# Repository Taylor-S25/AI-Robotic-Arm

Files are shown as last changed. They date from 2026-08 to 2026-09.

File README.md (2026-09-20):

# Robotic-Arm/Gripper

Design and development of an Arduino controlled robotic arm/gripper

### Introduction & Goals

Inspired by Iron Man, this project explores the design of a robotic arm and how it can act as an extra pair of hands for simple tasks. The project combines mechanical design, CAD, prototyping and electronic control, with the long-term goal of exploring AI-assisted control.

The Problem this project it trying to address is fatigue. This robotic arm is to provide assistance to the user hence they can receive an extra pair of hands when needed. 

This project is currently in the last stage of its development as the assembly just needs to be upgraded with servo control as I am currently waiting for ordered parts. 

Tools, components and manufacturing methods:
- PTC Creo for CAD development
- 3D printing for manufacture
- Velxio for simulation control
- Arduino, servomotors and potentiometers for motion control
- GitHub for Project documentation 

Final outcome: A working robotic gripper assembly with servo motor control. Designed in Creo, tolerance tested through 3D printing iterations, and documented on GitHub

Goal 1: Robotic Arm must achieve mechanical motion 
 Result: The servomotors rotated the elbow joints by at least 60 degrees

Goal 2: Fabricte a physical prototype 
  Result: CAD components were 3D printed 

Goal 3: Implement basic control circuitry  
  Result: wired a potentiometer to a servomotor and controlled it with an Arduino  

## Initial Architecture design and features
<p align="center">
  
  
</p>
Early concept sketch showing arm structure joint movement and gripper mechanism.

# Contents

- [Project Overview & Requirements](#Project-Overview--Requirements)
- [Constraints](#Constraints)
- [Used Tools & Components](#Used-Tools--Components)
  - [CAD & Mechanical Design](#CAD--Mechanical-Design)
  - [Actuation, Electronics & Control](#Actuation-Electronics--Control)
  - [Manufacturing & Prototyping](#Manufacturing--Prototyping)
  - [Version Control & Documentation](#Version-Control--Documentation)
      - [Repository Structure](#Repository-Structure)
- [Design Development & Iteration](#Design-Development--Iteration)
  - [Tolerances, Fits & Interfaces](#tolerances-fits--interfaces)
- [Testing & Validation](#Testing--Validation)
- [Demo](#Demo)
- [What Breaks / Current Limitations](#What-Breaks--Current-Limitations)
- [Future Development](#Future-Development)
- [Conclusion](#Conclusion)

## Project Overview & Requirements

The Robotic arm/gripper is intended to be able to pick up and move small lightweight objects using servocontrolled motion. The project has been designed to have 4 joint and 5 degrees of freedom. The current version is only has 4 degrees of freedom and 3 joints with the ability to move with servomotor control. The project current stage is fully developed. The Robotic arms requirements are:

- to move at least 60 degrees of motion at each joint
- to be a physical model
- to cost no more than £50
- to use circuitry
- to be able to pick up and grip objects
- to have at least 2 degrees of freedom
- to have appropriate measurements
- to have appropriate coding

I have met the first requirement due to my [final demo](#Demo) which demonstrates that the robotic arm prototype can move 64 degrees. I have also met the second, third and forth requirements as I have 3D printed my robotic arm and have used circuitry such as microcontrollers, servomotors and potentiometers to bring my design to life, whilst keeping under my budget. Requirements 6 and 7 have also been met as the final products shows at least 2 degrees of freedom and appropriate measurements due a clearance of ±0.4mm being used.

Requirements I haven't met are 5 and 8 as I didn't have the money to 3D print the robotic gripper head meaning that only a simulation could be shown to display its objected lifting capabilities meaning that this requirement can't be completely validated. Therefore if I had to redo the project I would make a physical gripper head to validate this. Another requirement I didn't meet was appropriate coding as I used AI to create this C++ code, I haven't learned how to use C yet although I do know how to use Python and MATLABS. Hence, if I had to redo the project I would learn to use C++ before hand so I could validate this programming as my own.

## Constraints

Budget: £50 was the maximum amount of money I was willing to spend on this project. This stopped me from being able to 3D print the gripper head of the robotic arm, as I would have gone over budget. Hence I could only 3D print the body for the prototype. Therefore, I decided to simulate how the gripper works as a substitute. 

Time: The projects deadline was mid September 2026 with a project window frame of about 6 weeks

Hardware: For this project, I worked primarily with a standard Laptop and iPad. This limited me in simulating how my Robotic arm would react to stress and thermal analysis as simulation required an NVIDIA GPU. furthermore, this project caused me to borrow Arduino, servomotors, potentiometers and more from my university. 

Manufacturing: Manufacturing for the robotic arm was completed at my university as I didn't own a 3D printer. Black PLA filament was used for modelling. CAD parts were turned into STL files and exported to the device using a flash drive which I had to purchase, reducing my budget.

Geometry / packaging: The robotic arm was limited due to the size of the wings on each servomotor. Hence I had to order servo linkages off Amazon to attach each members to each servomotor causing a reduction in my budget that could have been spent else where.

Safety / reliability: Safety and reliability limits involved the circuitry not being built into the robotic arms design. Hence loose wiring occurring was greater meaning that the devices function could fail. 

## Used Tools & Components

- PTC Creo was used for CAD as I already knew how to use this software. Creo covers modelling, assemblies and drawings in one place making it a good choice for the robotic arms design. An alternative I thought about using was SolidWorks as I have experience with this software but haven’t used it in 2 years hence, I chose Creo.
 
- 3D printing was used to physically manifest parts. This went hand in hand with my CAD modelling as I could copy the designs into STL files used for quick and easy printing. Making it the strongest option. An alternative I thought about was cutting foam using a hot wire cutter, but this wouldn’t have been passive work and would have taken up a lot of time meaning I could have fallen behind schedule.
  
- Arduino was used for driving the servomotors when an input was given to the potentiometers. This allowed me to control the rotation of the robotic arm’s members. Components were connected via wiring through a breadboard. An alternative I thought about using was a Raspberry Pi, but this was far too complex than what I needed.
  
- Servomotors were used for controlling the members of the robotic arm. These were connected to each member via metal rods. An alternative I thought about using was a DC motor, but its torque was too low.
  
- GitHub was used to document my project as it provided branching which allowed me to update my progress without affecting the main database until I was ready.
  
- Velxio was a simulator I used for designing my circuitry before I assembled it physically. This helped me to design it physically

[AI Arduino source code](Physical%20and%20software%20simulations/sketch.ino)  
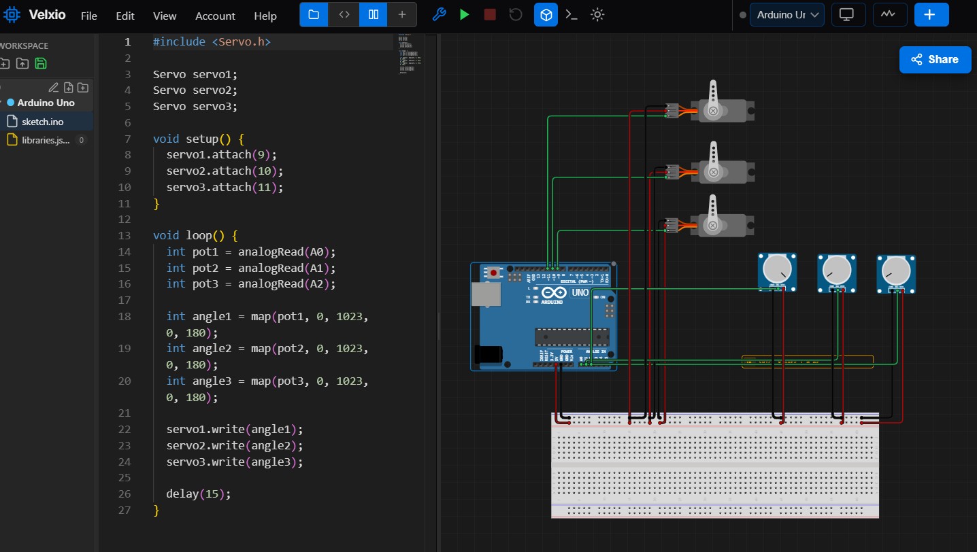
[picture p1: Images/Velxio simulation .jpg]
Velxio simulation


## CAD & Mechanical Design

CAD software used: PTC Creo, was used as it was the software I have the most expirience with. 

Overall assembly: The Over all assembly features around 20+ parts with some parts being used more than once. Two assemblies were created the gripper head and the Robotic arm. The mechanism had 5 degrees of freedom. 
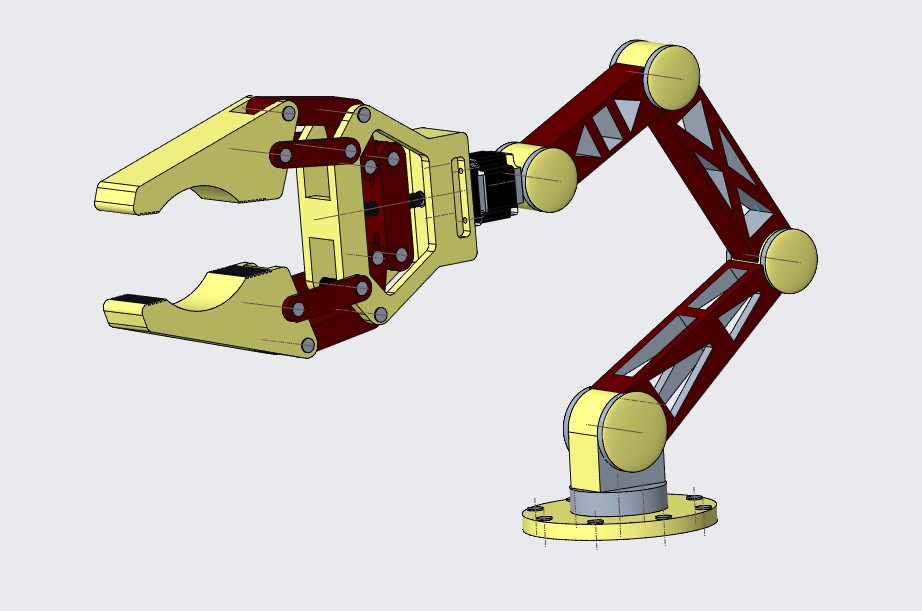
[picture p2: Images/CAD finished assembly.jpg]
CAD Assembly


Key mechanisms: Gripper assembly, small arm, medium arm, large arm, base joint, base plate

Motion / mechanism analysis: Checked rotary motion at each joint, at extreme angles there were limits but this was a desired outcome to avoid clashing.

Engineering drawings: All the [3D printing parts](3D%20printing%20parts/) needed drawing due to tolerancing required for smooth connections when 3D printing.

Design trade-offs: To ensure that the members were as light as possible, for smoother servomotor control, this involved removing as much material as possible making the parts weaker. However, this made the cost to print cheaper saving money. 

Alternative designs considered: Only using a 2 member design was something I had considered as it made the design more simplistic and cheap. However this reduced the robotic arms reach making it less practical. Therefore, I gave the design 3 members. For the gripper head I thought about using gears but this seemed too complicated for the design so I stuck with servo driven motion. 

## Actuation, Electronics & Control

Microcontroller: ELEGO UNOR3 - its role was to turn code into a set of instructions between the potentiometer and the servomotor causing motion. This was suitable as it provided enough voltage and amplitude for the job.

Actuators: Used standard hobby servomotor model S3003 for simple motion control

User input: Turning Potentiometer 

Power: The circuitry was powered via my laptop and a booster I bought to prevent the microcontroller's fuse from blowing

Wiring: Standard ELEGO male-male wiring was used to connect each component to the breadboard

Control logic: Input (potentiometer is turned), microcontroller (ELEGO processes input to produce the required output using code), Output (servomotor rotates)
### physical Arduino-servo simulation
https://github.com/user-attachments/assets/86161a06-1482-4143-b839-d0289b86b35f

safety limits: servomotors were placed inside members to prevent damage and servo-rotation was limited to prevent collisions.

## Manufacturing & Prototyping

As there were so many parts to print, this would have cost a lot of money, hence I could only print the main parts of the robotic arm. This excluded bearings and rods as well as the gripper head.  The gripper head was very intricate and would have taken a lot of time and resources to print, so I simulated it instead. Manufacturing limitations led to me altering the original parts making them easier to 3D print. As hovering displayed in the initial designs would have caused the software to produce lots of supports causing rough surfaces and greater friction reducing smooth servo control. 

Parts were assembled and disassembled due to panels pinned at each joint which ensured the members stayed connected. Each connection point had a tolerance of ± 0.4mm so everything attached smoothly. On my first print of the Robotic arm failed to integrate this, hence reprints were done. The cost for this was around about £20 worth of materials for both sets of prints. 

### Initial 3D print failure


## Version Control & Documentation

Explain how GitHub is used to organise the project. GitHub has been the central place for where I have organised all my work. I have structured files for CAD, 3D printing, Images, modifications and simulations. I have used the README to explain, what I did in the project as well as how and why for a plethora of decisions.

### Repository Structure
- STL files modified for 3D printing can be found [here](3D%20printing%20parts/)
- CAD parts and assemblies can be found in the working directory [here](Creo%20project/)
- Images documenting the project can be found [here](Images/)
- Modified Parts for clearance, cost and weigh can be found [here](Modified%20parts%20for%20tolerances/)
- Simulations for CAD, Arduino and the final product can be found [here](Physical%20and%20software%20simulations/)
- README for the project story: goals, decisions, evidence, results, limitations and next steps can be found [here](README.md)

By using branches I updated a copy of the main repository. This allowed me to edit my README and filing by adding or deleting things. If I liked the work I completed with this branch, I could then merge it with the original to make it the main branch. If I didn't I could then discard the branch whilst keeping the initial main the same.

Each edit caused by pushing new material to the origin was apart of my iterative design and if you go to my profile you can see all of the tweaks I made to this project throughout its life.

## Tolerances, Fits & Interfaces

Initially all the connected parts for the Robotic arm had no clearance. Using a clearance was something I probably should have thought about in the initial 3D print. This meant that the first print was too tight causing a lot of friction stopping smooth servomotor control. This led to me to modify CAD parts for manufacturing purposes. This involved removing material for light weight and cost and using a clearance of ±0.4mm. This made it easier for the servomotors to move and lift the adjacent material. This helped me to learn that every time you design something, a tolerance should always be used in manufacture, otherwise components may not fit together as designed.

## Testing & Validation

Testing was completed non-destructively. Non-destructively the objective was to see if the project could rotate at least 60 degrees, this was mentioned at the start in my goals. To measure this I used a protractor the arm manage to move around 64 degrees and couldn't move any further. A limitation was the servomotors as they could only rotate 180 degrees. If I had to do the test again i would have used a different type of servomotor that could move 360 degrees. Hence each member would have been able to rotate further.

Furthermore, I used non-destructive testing to assess the gripper head this was using CAD software as I couldn't 3D print the gripper. The objective was to use a servomotor to get the jaws of the gripper head to open and close. 

https://github.com/user-attachments/assets/3b3507d3-5217-4580-a304-04e4b8625a54

The result was that the gripper could open and close prefectly. A limitation of this is that I couldn't produce it physically hence I don't know truly if it would work. Therefore, if I had to do redo the project I would get more funding to print out the gripper. 

## Demo

This is a demo of the final product it shows me moving two of the robotic arms members using potentiometers and servomotors connected via a breadboard and microcontroller. This was were my robotic arm cam to life!

### Robotic Arm Project Final Demonstration
https://github.com/user-attachments/assets/79b7d7dd-8787-4b34-adfd-126fe1583319

## What Breaks / Current Limitations

-	One limit I reached was using more than 2 servomotors for the main prototype I would have liked to use 4. However, this would have involved massive changes CAD design and manufacture to allow for the servomotors to be integrated into the base plate and base joints. Hence if I had to produce a 3rd model, I would do that.
  
-	Another limit was the gripper head being printed. This would have taken a lot of time and money to produce due to there being so many parts. Hence if I had to produce another prototype, I would have increase my budget and extended my deadlines, to account for a clearance alteration, the time taken and cost to print.
  
- Currently nothing destructively breaks but servo motion is limited as there on no slots for the servos to work smoothly with. Theis is due to metal rods connecting the servos to each member become tight. This puts pressure on the servomotors causing them to move themselves as they aren’t fixed. Hence, for my next version I will fix the servos and add a slot in each member for the rods to move in.

## Future Development

Mechanical improvement: To 3D print the gripper head and attach it to the gripper arm so it looks more like the CAD model

Electronics improvement: To add additional servomotors and using slotting for better servo motion 

Additional testing: To simulate the gripper head physically and not just on CAD.

Long-term development: To use AI-assisted control - use and AI to decide whether the robotic arm should pick something up or not.

## Conclusion

Overall, this project has provided an opportunity to apply the engineering design process from an initial design to a functional prototype. Looking back at my 3 goals I managed to achieve all of them as I created a robotic gripper which could rotate at least 60 degrees, fabricated a physical prototype and used basic circuitry in the final design.

Major engineering decisions that made the biggest difference was using a clearance and removing material for a lighter and cheaper product. This iteration allowed me to save money and produce smooth servomotor control and taught me to apply these things straight away for future projects.

Something that the Prototyping taught me that CAD alone did not was that using a clearance in a physical prototype is imperative whereas in a CAD assembly it is not. Hence, always account for real world problems as a stimulatory drawing cannot account for every issue.

The biggest challenge I faced was using circuitry as I have never been taught mechatronics. Therefore, this was a challenge that taught me a lot about microcontrollers and circuits. Hence, I now feel more confident in using them now and in the future. 

If I had to start the project again and change something I would give myself a larger time frame and a bigger budget to complete the robotic arm/gripper. As then I might have been able to make the gripper giving the project greater validation.

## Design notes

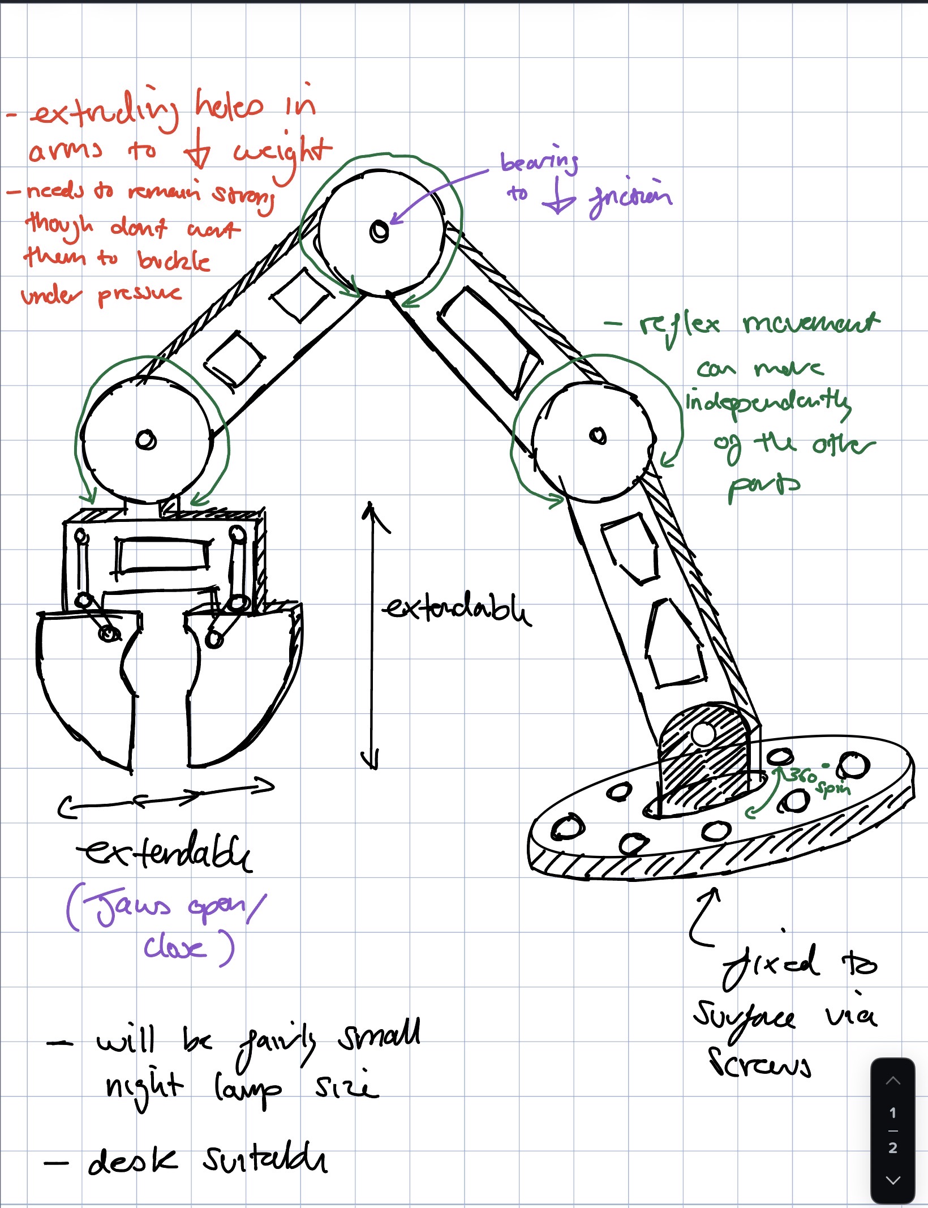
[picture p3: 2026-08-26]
Images/Initial sketch before CAD.jpg

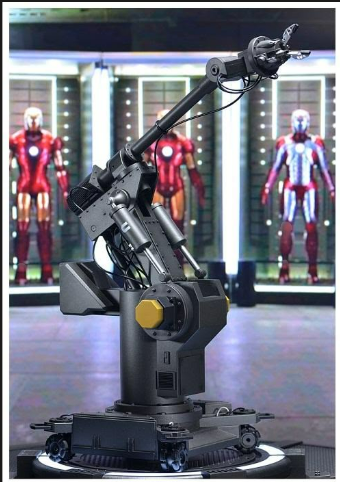
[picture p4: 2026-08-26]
Images/Iron Man inspiration.png

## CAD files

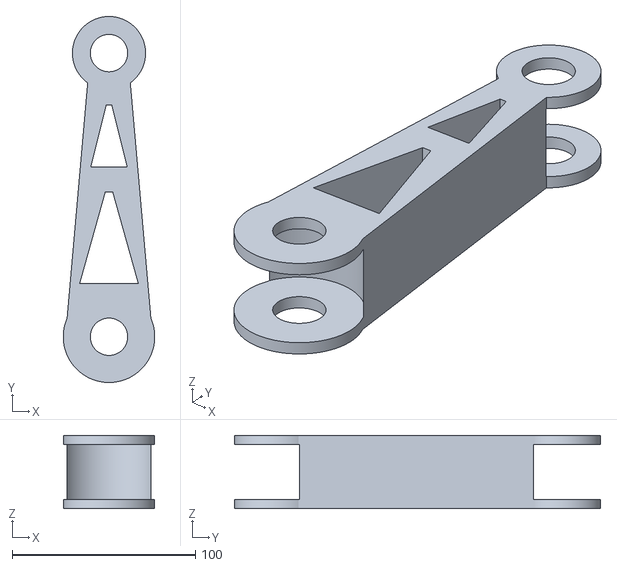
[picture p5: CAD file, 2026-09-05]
3D printing parts/large_arm.stl
50.0 x 200.0 x 40.0

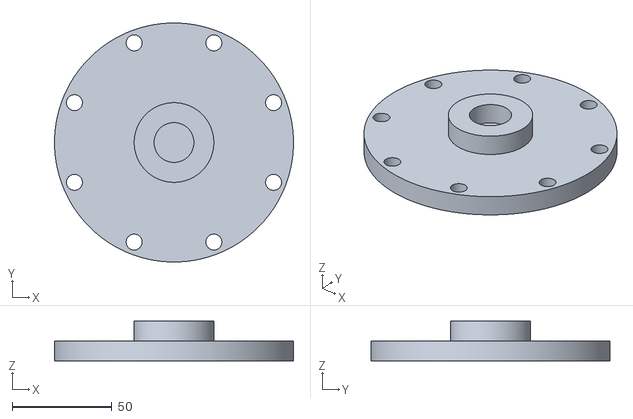
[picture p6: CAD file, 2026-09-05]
3D printing parts/base_plate.stl
120.0 x 120.0 x 20.0

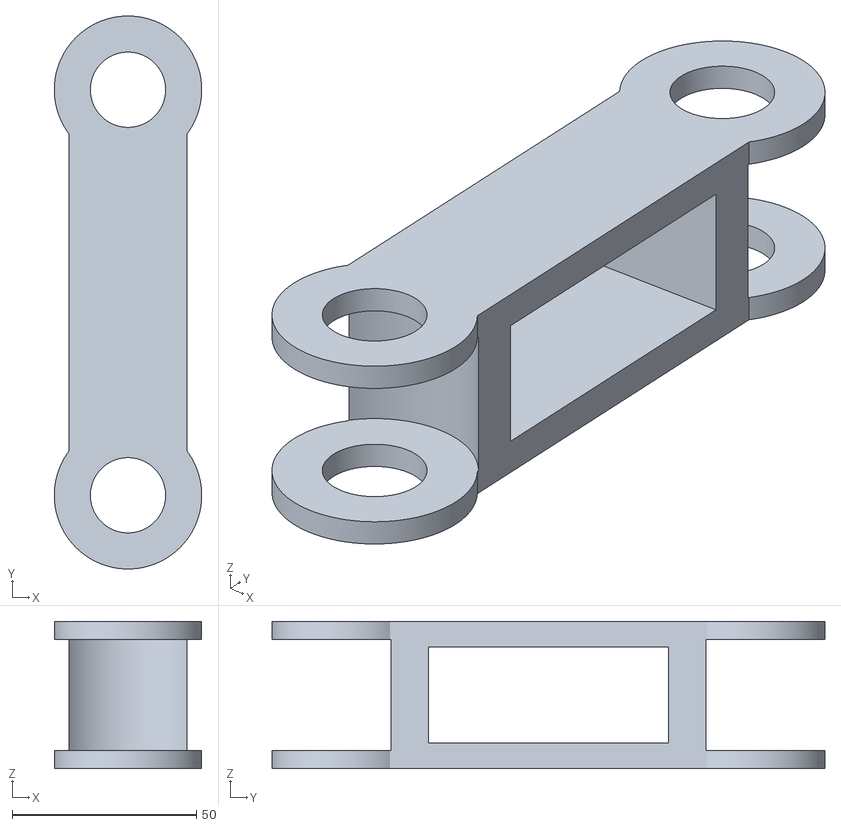
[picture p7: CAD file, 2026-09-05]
3D printing parts/small_arm.stl
40.0 x 150.0 x 40.0

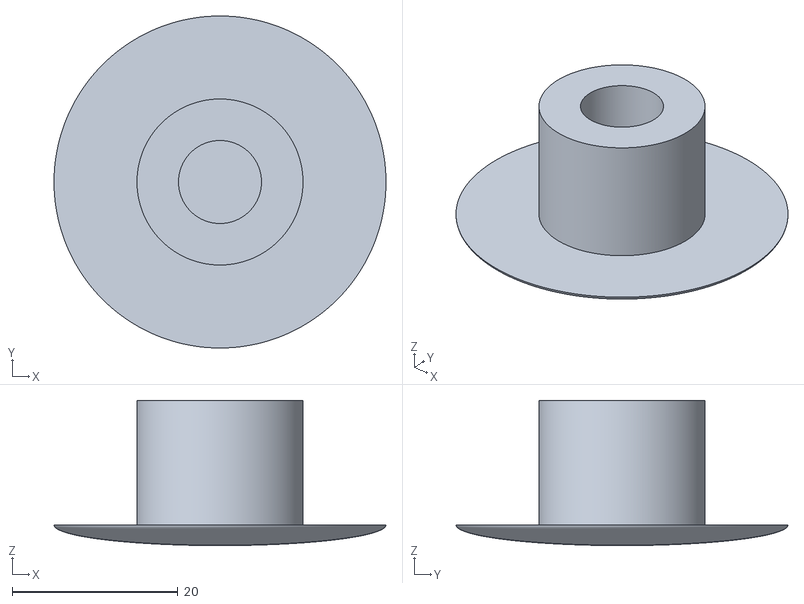
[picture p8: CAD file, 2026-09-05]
3D printing parts/pannel_small.stl
40.0 x 40.0 x 17.5

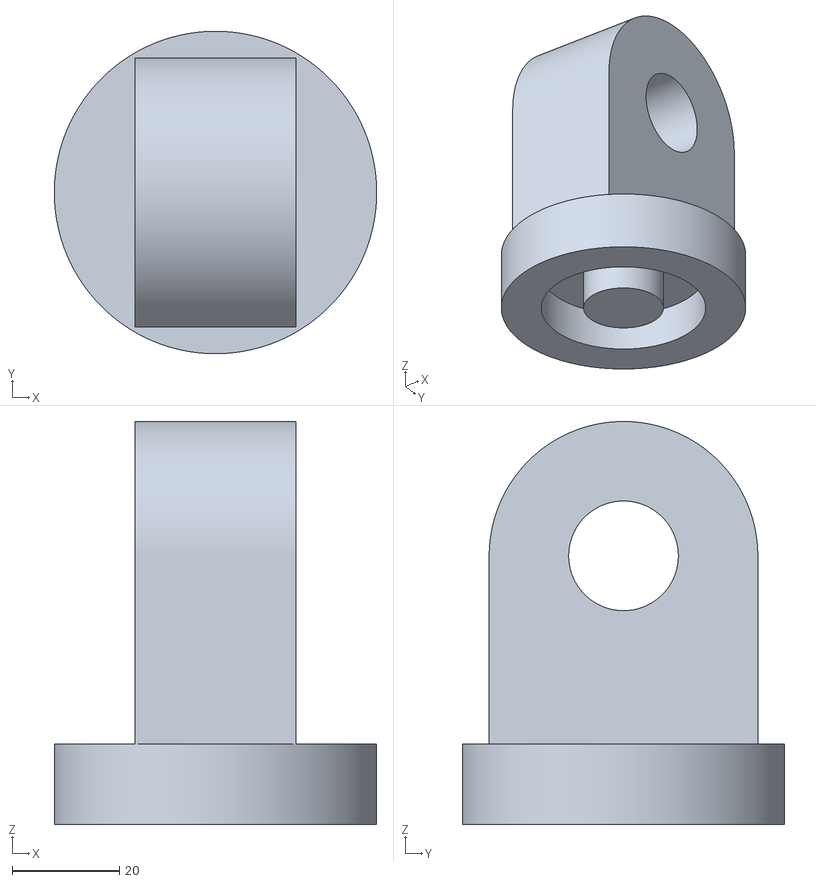
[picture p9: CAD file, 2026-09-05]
3D printing parts/bottom_joint.stl
60.0 x 60.0 x 75.0

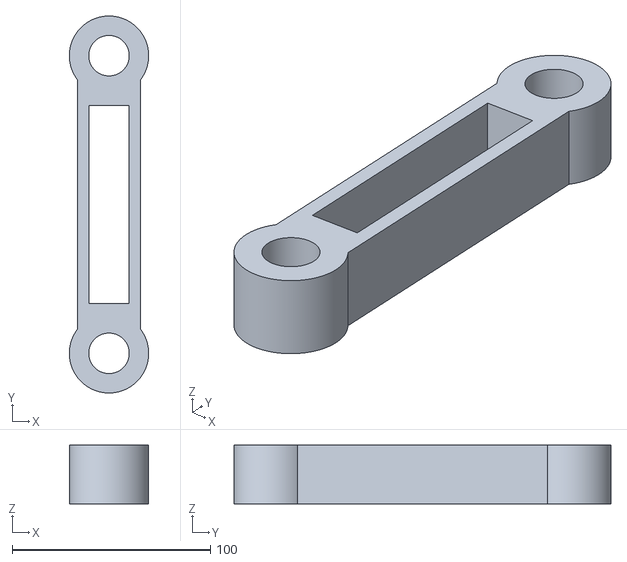
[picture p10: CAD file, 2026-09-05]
3D printing parts/medium_arm.stl
40.0 x 190.0 x 29.6

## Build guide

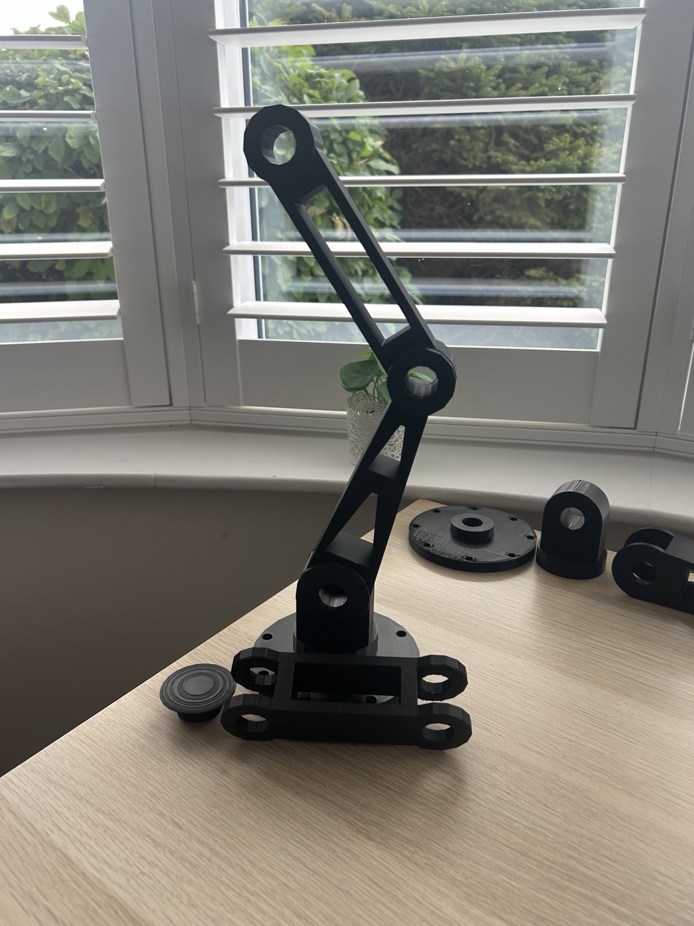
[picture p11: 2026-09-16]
Images/Initial 3D print.jpeg

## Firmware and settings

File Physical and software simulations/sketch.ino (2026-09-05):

#include <Servo.h>

Servo servo1;
Servo servo2;
Servo servo3;

void setup() {
  servo1.attach(9);
  servo2.attach(10);
  servo3.attach(11);
}

void loop() {
  int pot1 = analogRead(A0);
  int pot2 = analogRead(A1);
  int pot3 = analogRead(A2);

  int angle1 = map(pot1, 0, 1023, 0, 180);
  int angle2 = map(pot2, 0, 1023, 0, 180);
  int angle3 = map(pot3, 0, 1023, 0, 180);

  servo1.write(angle1);
  servo2.write(angle2);
  servo3.write(angle3);

  delay(15);
}

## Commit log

2026-08-25 initial commit robotic arm CAD project
2026-08-26 Create Initial scetch before CAD.jpg
2026-08-26 Enhance README with project overview and goals
    Added project overview and long-term goals for AI-Robotic-Arm.
2026-08-31 minor changes + 3D printing parts
    [arm1_cheap.stl, arm3_cheap.stl, arm_alter.stl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]
2026-09-05 changes for 3D printing + simulation
    [arm1_cheap.stl, arm3_cheap.stl, arm_alter.stl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]
2026-09-16 updated of simulations and 3D prints
2026-09-16 Rename project to Robotic-Arm/Gripper
    Updated project title and description to reflect Arduino control.
2026-09-17 Revise tools and components descriptions in README
    Updated the 'Used Tools & Components' section to provide detailed explanations of tools and alternatives considered for the robotic arm project.
2026-09-17 Fix image link for initial 3D print
    Updated image link for the initial 3D print in README.
2026-09-18 Create Robotic Arm Project Final Demonstration.mp4
2026-09-18 Fix anchor link case for Tolerances section
    Updated the link for 'Tolerances, Fits & Interfaces' to use lowercase in the anchor.
2026-09-18 Fix typo in demo link for Robotic Arm Project
    Corrected the spelling of 'Demonstration' in the demo link.
2026-09-19 Update README with project overview and requirements
    Added project overview and requirements for the robotic arm/gripper.
2026-09-19 Revise README with project overview and constraints
    Updated project overview to clarify robotic arm capabilities and requirements. Added details on current project status and constraints due to budget limitations.
2026-09-20 Update README with demo video link
    Added a link to the robotic arm project demonstration video.
2026-09-20 Revise demo section in README.md
    Updated the README to include a link for the final demonstration of the robotic arm project and removed the previous video link.
2026-09-20 Enhance README with gripper testing information
    Added details about the gripper head testing and results, including a link to the CAD simulation.
2026-09-20 Remove duplicate links from README.md
    Removed duplicate AI Arduino source code and Velxio simulation links from the Manufacturing & Prototyping section.
